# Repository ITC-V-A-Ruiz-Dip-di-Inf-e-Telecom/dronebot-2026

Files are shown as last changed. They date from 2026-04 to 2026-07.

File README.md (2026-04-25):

# Dronebot 2026 — Team Holly

Documentazione tecnica integrale del sistema di rilevamento fuoco e coordinamento rover per la gara Dronebot 2026.
Il sistema e' composto da due sottosistemi che comunicano via rete WiFi: uno **Script PC** per il rilevamento tramite drone DJI NEO 1, e un **Rover autonomo** guidato da Raspberry Pi 5 e Arduino Mega Keyestudio.

- **Istituto:** ITC Vincenzo Arangio Ruiz — Roma
- **Dipartimento:** Informatica e Telecomunicazioni
- **Team:** TEAM HOLLY

---

## Indice

1. [Come funziona](#come-funziona)
2. [Pipeline Completa del Sistema](#pipeline-completa-del-sistema)
3. [Pseudocodice](#pseudocodice)
4. [Il Rover Holly](#il-rover-holly)
5. [Firmware Arduino Mega V12.11](#firmware-arduino-mega-v1211)
6. [Script Raspberry Pi 5 V13.9](#script-raspberry-pi-5-v139)
7. [Configurazione OS Raspberry Pi](#configurazione-os-raspberry-pi)
8. [Prerequisiti](#prerequisiti)
9. [Installazione](#installazione)
10. [Connessione con RTMP live streaming](#connessione-con-rtmp-live-streaming)
11. [Connessione del dispositivo Android](#connessione-del-dispositivo-android)
12. [Configurazione PC](#configurazione)
13. [Utilizzo](#utilizzo)
14. [Generazione marker ArUco](#generazione-marker-aruco)
15. [BOM — Bill of Materials](#bom--bill-of-materials)
16. [SBOM — Software Bill of Materials](#sbom--software-bill-of-materials)
17. [Risoluzione problemi](#risoluzione-problemi)
18. [Licenza](#licenza)

---

## Come funziona

La gara si svolge in due fasi gestite automaticamente dallo script.

### Fase 1 — Rilevamento del fuoco

Il pilota porta il drone sull'area di fuoco. Lo script usa YOLO per rilevare il fuoco in tempo reale.
Quando la rilevazione e' stabile per `FIRE_CONFIR_FRAMES` frame consecutivi l'incendio viene confermato, viene salvata una foto come prova e viene inviato il **Segnale 1** al rover via HTTP.
Il rover riceve il segnale e inizia a prepararsi per il tracciamento.

### Fase 2 — Coordinamento rover

La Fase 2 puo' concludersi in due modi distinti, garantendo ridondanza operativa.

**Percorso A — Verifica automatica completa (primario)**

Il pilota torna nell'area del rover. Il rover inizia a seguire il drone tramite il LED IR. Il pilota riporta lentamente il drone sopra l'area di fuoco e lo mantiene fermo.

**Fase 2a — Blocco del cerchio:** Lo script rileva nuovamente il fuoco e, quando la posizione e' stabile per `FIRE_LOCK_FRAMES` frame consecutivi, blocca il centro e il raggio del cerchio di fuoco come riferimento preciso. Questo riferimento e' piu' accurato di quello della Fase 1 perche' il drone e' esattamente sopra il fuoco alla quota di verifica.

**Fase 2b — Verifica contenimento ArUco:** Lo script verifica che tutti e quattro gli angoli del marker ArUco montato sul rover siano all'interno del cerchio bloccato. Il centro del cerchio viene aggiornato frame per frame per compensare il leggero drift del drone in hovering. Quando la condizione e' soddisfatta per `ROVER_CONFIRM_FRAMES` frame consecutivi, il contenimento viene confermato, viene salvata la foto finale come prova e viene inviato `/stop` al rover via HTTP.

**Percorso B — Ridondanza passiva (se pilota esperto)**

Se le condizioni lo permettono, il rover segue il drone direttamente nell'area di fuoco senza passare per il lock o la verifica ArUco: le Fasi 2a e 2b vengono saltate interamente. Quando il drone esce dall'inquadratura, il thread `vision_logic` non rileva piu' il LED IR e imposta `comando_led = X`. Il rover si ferma autonomamente nella posizione corrente all'interno del cerchio di fuoco. I due percorsi sono indipendenti: la ridondanza garantisce il completamento anche in caso di perdita del segnale video.

---

## Pipeline Completa del Sistema

Il flusso completo dei dati, dall'acquisizione video del drone fino ai motori del rover.

### Lato PC

```mermaid
---
config:
  layout: elk
---
flowchart TD
    classDef drone stroke:#b45309,fill:#fef3c7,color:#78350f
    classDef comm stroke:#b91c1c,fill:#fee2e2,color:#7f1d1d
    classDef process stroke:#6d28d9,fill:#ede9fe,color:#4c1d95
    classDef phase stroke:#1d4ed8,fill:#dbeafe,color:#1e3a8a
    classDef evidence stroke:#15803d,fill:#dcfce7,color:#14532d

    DJI["DJI NEO 1\nDrone — camera gimbal"]:::drone
    FLY["DJI FLY\nApp Android\nAbilita Live Streaming RTMP"]:::comm
    FF["ffmpeg\nServer RTMP porta 1935\nRiceve video e scrive su v4l2"]:::process
    V4L["v4l2loopback\n/dev/video10\nWebcam virtuale nel kernel"]:::process
    MAIN["src/main.py\ncv2.VideoCapture\nLoop principale di rilevamento"]:::process

    DJI -->|video feed| FLY
    FLY -->|rtmp://IP_PC:1935/live/drone| FF
    FF -->|frame video| V4L
    V4L -->|VideoCapture| MAIN

    MAIN --> F1["FASE 1\nYOLOv8 rileva il fuoco\nConferma su 7 frame stabili\nFIRE_CONFIR_FRAMES = 7"]:::phase
    F1 -->|FUOCO CONFERMATO| EV1["Salva foto prova\nevidence/"]:::evidence
    EV1 --> S1["HTTP POST /start\nRaspberry Pi :5000\nRover inizia a muoversi"]:::comm

    S1 --> F2A["PERCORSO A — FASE 2a\nDrone ritorna sul fuoco\nAggancio preciso del cerchio\nFIRE_LOCK_FRAMES = 20"]:::phase
    S1 -.->|"PERCORSO B\nse rover gia' nell'area"| PASS["Drone esce dal frame\ncomando_led = X\nRover si ferma nell'area di fuoco\n2a e 2b saltate"]:::evidence
    F2A -->|CERCHIO AGGANCIATO| F2B["FASE 2b\nRileva marker ArUco sul rover\nVerifica che sia dentro il cerchio\nROVER_CONFIRM_FRAMES = 5"]:::phase
    F2B -->|CONTENIMENTO CONFERMATO| EV2["Salva foto finale\nevidence/"]:::evidence
    EV2 --> S2["HTTP POST /stop\nRaspberry Pi :5000"]:::comm
    S2 --> FIN["GARA COMPLETATA"]:::evidence
    PASS --> FIN
```

### Lato Rover

```mermaid
---
config:
  layout: elk
---
flowchart TD
    classDef raspberry stroke:#3730a3,fill:#e0e7ff,color:#1e1b4b
    classDef arduino stroke:#0f766e,fill:#ccfbf1,color:#134e4a
    classDef sensor stroke:#0369a1,fill:#bae6fd,color:#0c4a6e
    classDef control stroke:#6d28d9,fill:#ede9fe,color:#4c1d95
    classDef comm stroke:#b91c1c,fill:#fee2e2,color:#7f1d1d

    HTTP["/start ricevuto da PC\nstato_gara = IN_MARCIA"]:::comm

    subgraph RPI["Raspberry Pi 5 — holly_brain_v13.9.py"]
        VIS["Thread vision_logic\nPi Camera NoIR + Filtro R72\nrpicam-vid MJPEG\nThreshold 248 — blob LED IR\nposX determina direzione"]:::sensor
        LID["Thread lidar_thread\nYDLiDAR X4 Pro su /dev/ttyUSB0\nScansione 360 gradi a laser\nAggiorna punti_lidar ogni ciclo"]:::sensor
        LIST["Thread listener\nLegge telemetria da /dev/serial0\nFormato DATA:dF,dL,dR,dB,bSX,bDX\nAggiorna variabili globali ToF e bumper"]:::comm
        ADS_T["Thread ads_thread\nADS1115 via bus I2C\nMisura tensione batteria logica\nPartitore 10k/4.7k — ogni 1 secondo"]:::sensor
        ML["Main Loop 20 Hz\nFonde dati da tutti i thread\nApplica safety overrides\nDecide il comando finale"]:::control
    end
    class RPI raspberry

    HTTP --> RPI
    VIS -->|"posX<200 = A (sinistra)\nposX>440 = D (destra)\ncentro = W (avanti)\nnessun blob = X (stop)"| ML
    LID -->|punti_lidar 360 gradi| ML
    ADS_T -->|v_batteria| ML

    subgraph ARD["Arduino Mega — holly_mega_v12.11.ino"]
        TOF["4x Sensori VL53L0X ToF\nI2C indirizzi 0x30..0x33\nFrontale Destro Sinistro Posteriore\nDistanze in millimetri"]:::sensor
        BUMP["2x Bumper meccanici\npin 52 B_SX e pin 53 B_DX\nINPUT_PULLUP — LOW se premuto\nRilevamento urti fisici"]:::sensor
        VETO["VETO di Sicurezza Hardware\ndF<250mm o bumper premuto = STOP\ndB<200mm in retromarcia = STOP\ndL o dR<120mm in rotazione = STOP"]:::control
        DRV["L298N H-Bridge\nPWM su ENA pin10 e ENB pin5\nDirezione su IN1-IN4 pin 9-6\nVelocita' base vel=80 su 255"]:::control
        MOT["4x Motori DC 12V\nControllo differenziale\n2 motori SX e 2 motori DX"]:::control
    end
    class ARD arduino

    %% Feedback sensoriale verso VETO
    TOF -->|dF dL dR dB in mm| VETO
    BUMP -->|bSX bDX stato fisico| VETO
    VETO -->|comando sicuro| DRV
    DRV --> MOT

    %% Telemetria Arduino verso Raspberry Pi
    ARD -->|"DATA:dF,dL,dR,dB,bSX,bDX ogni 40ms"| LIST
    LIST -->|feedback ToF e bumper| ML

    %% Comando principale verso Arduino
    ML -->|"cmd_finale\nUART 115200 baud"| ARD
```

---

## Pseudocodice

### Script PC — Drone side (V13.x)

> **INIZIO**
>
> > Apri `VideoCapture` da `/dev/video10`
> >
> > Carica modello YOLOv8 `best.pt`
> >
> > Inizializza `ARUCODetector` — dizionario `DICT_4X4_50`, ID `10`
> >
> > Imposta `FASE = 1`
>
> **RIPETI all'infinito:**
>
> > Leggi frame dalla webcam virtuale
> >
> > SE frame non valido: `continua`
> >
> > **SE** `FASE == 1`:
> >
> > > Esegui YOLOv8 sul frame
> > >
> > > PER ogni detection con area `>= MIN_FIRE_AREA`:
> > >
> > > > Calcola spostamento centro rispetto al frame precedente
> > > >
> > > > SE spostamento `< MAX_FIRE_SHIFT`: `streak += 1`
> > > >
> > > > ALTRIMENTI: `streak = 0`
> > >
> > > SE `streak >= FIRE_CONFIR_FRAMES`:
> > >
> > > > Salva foto prova in `evidence/`
> > > >
> > > > `HTTP POST /start` → Raspberry Pi `:5000`
> > > >
> > > > `FASE = 2`
> >
> > **SE** `FASE == 2` E cerchio **non agganciato**:
> >
> > > Esegui YOLO → cerca detection con area `>= MIN_FIRE_AREA`
> > >
> > > SE trovata e spostamento stabile: `fire_lock_streak += 1`
> > >
> > > ALTRIMENTI: `fire_lock_streak = 0`
> > >
> > > SE `fire_lock_streak >= FIRE_LOCK_FRAMES`:
> > >
> > > > Calcola centro e raggio dalla bounding box
> > > >
> > > > Cerchio → **AGGANCIATO**
> >
> > **SE** `FASE == 2` E cerchio **agganciato**:
> >
> > > Aggiorna centro cerchio con nuova detection YOLO (drift compensation)
> > >
> > > Esegui `ARUCODetector` sul frame
> > >
> > > SE marker ArUco trovato:
> > >
> > > > SE tutti e 4 gli angoli sono nel cerchio: `rover_streak += 1`
> > > >
> > > > ALTRIMENTI: `rover_streak = 0`
> > > >
> > > > SE `rover_streak >= ROVER_CONFIRM_FRAMES`:
> > > >
> > > > > Salva foto finale in `evidence/`
> > > > >
> > > > > `HTTP POST /stop` → Raspberry Pi `:5000`
> > > > >
> > > > > **ESCI**
> >
> > Mostra frame a schermo
> >
> > SE tasto `ESC` o `Q`: **ESCI**
>
> **FINE**

---

### Firmware Arduino Mega (V12.11)

> **INIZIO**
>
> > Inizializza pin motori `ENA=10, ENB=5, IN1..IN4=9..6` come Output
> >
> > Inizializza pin bumper `B_SX=52, B_DX=53` come Input con Pull-up
> >
> > Porta tutti i pin XSHUT `14,15,16,17` a LOW — tutti i sensori spenti
> >
> > Avvia `Serial1` a 115200 baud verso Raspberry Pi
> >
> > Avvia bus I2C
> >
> > **AVVIO SEQUENZIALE SENSORI ToF:**
> >
> > > PER ogni sensore (Frontale, Destro, Sinistro, Posteriore):
> > >
> > > > Porta il pin XSHUT del sensore a HIGH
> > > >
> > > > Attendi 50 ms
> > > >
> > > > Assegna indirizzo I2C univoco `0x30, 0x31, 0x32, 0x33`
> > > >
> > > > Avvia lettura continua
>
> **RIPETI all'infinito:** (ciclo 40 ms ≈ 25 Hz)
>
> > Leggi `dF, dL, dR, dB` dai 4 sensori ToF in mm
> >
> > Leggi `bSX = (pin52 == LOW)`, `bDX = (pin53 == LOW)`
> >
> > SE `Serial1.available() > 0`: leggi carattere comando `(W, S, A, D, X)`
> >
> > ALTRIMENTI: mantieni l'ultimo comando ricevuto
> >
> > **VETO DI SICUREZZA:**
> >
> > > SE comando `W` E (`dF < 250` OPPURE `bSX` OPPURE `bDX`): `azione = X`
> > >
> > > SE comando `S` E `dB < 200`: `azione = X`
> > >
> > > SE comando `A` E `dL < 120`: `azione = X`
> > >
> > > SE comando `D` E `dR < 120`: `azione = X`
> > >
> > > ALTRIMENTI: `azione = comando`
> >
> > **ESECUZIONE MOVIMENTO:**
> >
> > > `W` → `muovi(+vel, +vel)` — avanti
> > >
> > > `S` → `muovi(-vel, -vel)` — indietro
> > >
> > > `A` → `muovi(-vel, +vel)` — rotazione sinistra
> > >
> > > `D` → `muovi(+vel, -vel)` — rotazione destra
> > >
> > > `Q` → `muovi(-vel/2, -vel)` — recupero baffo SX
> > >
> > > `E` → `muovi(-vel, -vel/2)` — recupero baffo DX
> > >
> > > `X` → `stoppa()`
> >
> > Invia su `Serial1`: `"DATA:dF,dL,dR,dB,bSX,bDX"`
> >
> > Attendi 40 ms
>
> **FINE**

---

### Script Raspberry Pi 5 (V13.9)

> **INIZIO**
>
> > Apri seriale `/dev/serial0` a 115200 baud verso Arduino
> >
> > Inizializza I2C → `ADS1115` canale A0
> >
> > `stato_gara = "ATTESA"`,  `punti_lidar = [5000] * 360`
> >
> > **AVVIA 5 THREAD DAEMON:**
> >
> > > `listener` — legge telemetria seriale dall'Arduino
> > >
> > > `vision_logic` — elabora frame camera, produce `comando_led`
> > >
> > > `lidar_thread` — legge scansione YDLiDAR 360°
> > >
> > > `ads_thread` — campiona tensione batteria ogni 1 s
> > >
> > > `run_flask` — serve dashboard web su porta 5000
>
> **MAIN LOOP** (20 Hz):
>
> > SE `stato_gara == "ATTESA"` OPPURE `comando_led == X`:
> >
> > > `cmd_finale = X`
> > >
> > > SE `b_sx` OPPURE `b_dx` OPPURE `timer_recupero > 0`:
> > >
> > > > SE `b_sx`: `(timer_recupero, last_side_hit) = (6, "SX")`
> > > >
> > > > SE `b_dx`: `(timer_recupero, last_side_hit) = (6, "DX")`
> > > >
> > > > `cmd_finale = Q` SE `last_side_hit == "SX"` ALTRIMENTI `E`
> > > >
> > > > `timer_recupero -= 1`
> >
> > ALTRIMENTI (IN_MARCIA e LED visibile):
> >
> > > `cmd_finale = comando_led`
> > >
> > > `dist_f_lidar = media(punti_lidar[175..185])`
> > >
> > > **A. Stop emergenza ToF frontale:**
> > >
> > > > SE `0 < tof_f < 100`: `cmd_finale = X`
> > >
> > > **B. ToF NUDGE — correzione laterale:**
> > >
> > > > SE `comando_led == W` E `0 < tof_l < 150`: `cmd_finale = D`
> > > >
> > > > SE `comando_led == W` E `0 < tof_r < 150`: `cmd_finale = A`
> > >
> > > **C. Aggiramento LiDAR:**
> > >
> > > > SE `cmd_finale == W` E `dist_f_lidar < 300`:
> > > >
> > > > > `varchi = [ang per ang in 130..230 se punti_lidar[ang] > 350]`
> > > > >
> > > > > SE varchi trovati: sterza verso il varco più vicino a 180°
> > > > >
> > > > > ALTRIMENTI: `cmd_finale = S`
> >
> > Scrivi `cmd_finale` sulla seriale → Arduino
> >
> > Attendi 50 ms
>
> **FINE**

---

## Il Rover Holly

Il rover e' un veicolo a 4 ruote motrici a controllo differenziale, progettato per seguire autonomamente il drone tramite una sorgente luminosa a infrarossi montata sul drone stesso.

### Architettura Hardware

```mermaid
---
config:
  layout: elk
---
flowchart TB
    classDef raspberry stroke:#3730a3,fill:#e0e7ff,color:#1e1b4b
    classDef arduino stroke:#0f766e,fill:#ccfbf1,color:#134e4a
    classDef sensor stroke:#0369a1,fill:#bae6fd,color:#0c4a6e
    classDef control stroke:#6d28d9,fill:#ede9fe,color:#4c1d95
    classDef power stroke:#b45309,fill:#fef3c7,color:#78350f

    subgraph LOGIC["Elettronica Logica — alimentata a 7.4V LiPo"]
        RPI5["Raspberry Pi 5\n8 GB RAM\nholy_brain_v13.9.py"]:::raspberry
        CAM["Pi Camera 3 NoIR Wide\nConnettore ISP\n+ Filtro Hoya R72 720nm\nIndividua il LED IR sul drone"]:::sensor
        LIDAR["YDLiDAR X4 Pro\n360 gradi 2D Laser\n/dev/ttyUSB0 USB\nEvita ostacoli in autonomia"]:::sensor
        ADS["ADS1115 16-bit ADC\nBus I2C — indirizzo 0x48\nMonitoraggio tensione batteria logica\nPartitore 10k/4.7k"]:::sensor
        BATT7["Batteria Logica\nLiPo 7.4V 2S 2700 mAh\nXell-Sport 30C"]:::power
        STEP["Step-Down XL4016E1\n7.4V a 5.2V 8A\nAlimenta tutta la logica"]:::control
        LS["Level Shifter Bidirezionale\n3.3V a 5V\nAdatta UART RPi-Arduino"]:::control
    end

    subgraph POWER["Elettronica Potenza — alimentata a 11.1V LiPo"]
        ARD["Arduino Mega Keyestudio\nholy_mega_v12.11.ino\nFirmware di basso livello"]:::arduino
        TOF["4x VL53L0X Time-of-Flight\nI2C 0x30 0x31 0x32 0x33\nFrontale Destro Sinistro Posteriore\nDistanze in millimetri"]:::sensor
        BUMP["2x Bumper meccanici\npin 52 B_SX e pin 53 B_DX\nRilevamento urti fisici diretti"]:::sensor
        L298["L298N H-Bridge\nMotor Driver duale\nGestisce 4 motori DC in coppia"]:::control
        MOT["4x Motori DC 12V\ncon ruote gommate\nControllo differenziale"]:::control
        BATT11["Batteria Potenza\nLiPo 11.1V 3S 1300 mAh\nXell-Light 20C"]:::power
    end

    CAM --- RPI5
    LIDAR --- RPI5
    ADS --- RPI5
    BATT7 --- ADS
    BATT7 --- STEP
    STEP -->|5.2V| RPI5
    RPI5 --- LS
    LS -->|UART 115200 baud| ARD
    ARD --- TOF
    ARD --- BUMP
    ARD --- L298
    L298 --- MOT
    BATT11 -->|11.1V diretti| L298
```

### Sistema di Alimentazione Duale

Il rover usa due batterie separate per isolare la logica dalla potenza:

| Batteria | Modello | Tensione | Uso |
|---|---|---|-----|
| Logica RPi | LiPo 7.4 V 2700 mAh 2S | 7.4 V → Step-Down → 5.2 V | Raspberry Pi 5 e sensori logici |
| Logica Arduino | LiPo 7.4 V 2200 mAh 2S | 7.4 V → Step-Down | Arduino Mega e periferiche |
| Potenza | Xell-Light 3S LiPo 11.1 V 1300 mAh | 11.1 V diretti | Motori DC 12 V tramite L298N |

Lo Step-Down XL4016E1 abbassa la tensione logica da 7.4 V a **5.2 V** (regolato con potenziometro per compensare il calo sotto carico e garantire stabilita' al Raspberry Pi 5). Il Level Shifter bidirezionale 3.3V ↔ 5V adatta i livelli logici della linea UART tra i due microcontrollori. L'ADS1115 monitora in tempo reale la tensione della batteria logica tramite un partitore resistivo (10 kΩ / 4.7 kΩ).

Sul connettore di bilanciamento della batteria logica RPi (7.4 V 2S) e' collegato un **tester LiPo con buzzer** impostato a **3.4 V per cella** come soglia di allarme sonoro: quando una delle celle scende sotto questa soglia il buzzer suona avvisando il team prima che la tensione raggiunga livelli critici per il Raspberry Pi.

### Sistema di Visione — Tracciamento LED IR

La logica di inseguimento sfrutta la combinazione di una telecamera priva di filtro IR (NoIR) e un filtro ottico passa-alto (Hoya R72, soglia 720 nm) per rendere visibile **solo** la luce infrarossa. Un singolo LED IR da 210 mW montato sul drone appare come l'unico punto luminoso nell'immagine, anche in ambienti illuminati.

```mermaid
---
config:
  layout: elk
---
flowchart TD
    classDef sensor stroke:#0369a1,fill:#bae6fd,color:#0c4a6e
    classDef process stroke:#6d28d9,fill:#ede9fe,color:#4c1d95
    classDef decision stroke:#b45309,fill:#fef3c7,color:#78350f
    classDef command stroke:#b91c1c,fill:#fee2e2,color:#7f1d1d
    classDef stop stroke:#374151,fill:#f1f5f9,color:#1f2937

    CAM["Pi Camera 3 NoIR Wide\nSensore senza filtro IR incorporato\nCaptura anche la luce infrarossa"]:::sensor
    FILT["Filtro Hoya R72 — 720nm\nBlocca tutta la luce visibile\nLascia passare solo l'infrarosso\nIl LED IR sul drone diventa l'unico punto luminoso"]:::sensor
    GRAY["rpicam-vid MJPEG\nFrame convertito in Grayscale 640x480\nBassa latenza per inseguimento real-time"]:::process
    THR["cv2.threshold — soglia 248\nSeleziona solo i pixel piu' luminosi\nElimina il rumore ambientale"]:::process
    MASK["Maschera binaria\nRegioni bianche = sorgenti IR intense\nTutto il resto = nero"]:::process
    CNT["cv2.findContours\nIndividua le regioni connesse\nOrdinate per area decrescente"]:::process
    AREA{"Area blob valida?\n15 px < area < 2000 px\nSoglia anti-rumore e anti-saturazione"}:::decision
    STOP["comando_led = X\nSTOP — LED assente\no blob troppo grande o piccolo"]:::stop
    POS["Calcola centroide\nposX = M10 diviso M00\nPosizione orizzontale del LED nel frame"]:::process
    L{"posX < 200?\nLED nel terzo sinistro"}:::decision
    A["comando_led = A\nSterzata sinistra\nIl rover ruota per centrare il LED"]:::command
    R{"posX > 440?\nLED nel terzo destro"}:::decision
    D["comando_led = D\nSterzata destra\nIl rover ruota per centrare il LED"]:::command
    W["comando_led = W\nAvanti dritto\nLED nella zona centrale 200..440 px"]:::command

    CAM -->|frame raw| FILT
    FILT --> GRAY
    GRAY --> THR
    THR --> MASK
    MASK --> CNT
    CNT --> AREA
    AREA -->|No — LED non rilevato| STOP
    AREA -->|Si — blob valido| POS
    POS --> L
    L -->|Si| A
    L -->|No| R
    R -->|Si| D
    R -->|No| W
```

---

## Firmware Arduino Mega V12.11

File: `rover/arduino/holly_mega_v12.11.ino`

### Pinout Completo

| Categoria | Pin | Funzione |
|---|-----|---|
| Motori L298N | 10, 5 | ENA, ENB — velocita' PWM (0–255) |
| Motori L298N | 9, 8 | IN1, IN2 — direzione motore SX |
| Motori L298N | 7, 6 | IN3, IN4 — direzione motore DX |
| ToF XSHUT | 14 | X_F — accensione sensore Frontale |
| ToF XSHUT | 15 | X_R — accensione sensore Destro |
| ToF XSHUT | 16 | X_L — accensione sensore Sinistro |
| ToF XSHUT | 17 | X_B — accensione sensore Posteriore |
| Serial1 | 18 | TX1 — trasmissione verso Raspberry Pi (via Level Shifter bidirezionale) |
| Serial1 | 19 | RX1 — ricezione da Raspberry Pi (via Level Shifter bidirezionale) |
| Bumper | 52 | B_SX — micro-switch sinistro (INPUT_PULLUP) |
| Bumper | 53 | B_DX — micro-switch destro (INPUT_PULLUP) |

### Inizializzazione ToF (Risoluzione Conflitti I2C)

Tutti i sensori VL53L0X escono dalla fabbrica con lo stesso indirizzo I2C (`0x29`). Per distinguerli sul bus, il firmware li accende uno alla volta:

```cpp
void initTof(VL53L0X &s, int pin_xshut, uint8_t nuovo_indirizzo) {
    digitalWrite(pin_xshut, HIGH);  // accende solo questo sensore
    delay(50);
    if (s.init()) {
        s.setAddress(nuovo_indirizzo); // assegna indirizzo univoco
        s.setTimeout(200);
        s.startContinuous();
    }
}
// Avvio sequenziale:
// initTof(sF, X_F, 0x30)  → Frontale
// initTof(sR, X_R, 0x31)  → Destro
// initTof(sL, X_L, 0x32)  → Sinistro
// initTof(sB, X_B, 0x33)  → Posteriore
```

### Logica VETO — Sicurezza Hardware

Il VETO e' la funzione di sicurezza piu' critica: sovrascrive i comandi ricevuti dal Raspberry Pi prima che arrivino ai motori. Opera a livello firmware senza ritardi di rete.

| Condizione | Soglia | Azione |
|---|---|---|
| Comando `W` + `dF < 250 mm` | 25 cm | Forza `X` (stop) |
| Comando `W` + bumper premuto | — | Forza `X` (stop) |
| Comando `S` + `dB < 200 mm` | 20 cm | Forza `X` (stop) |
| Comando `A` + `dL < 120 mm` | 12 cm | Forza `X` (stop) |
| Comando `D` + `dR < 120 mm` | 12 cm | Forza `X` (stop) |

La soglia laterale e' volutamente piu' bassa (12 cm vs 25 cm) per permettere manovre in corridoi stretti.

### Controllo Motori

```cpp
void muovi(int sinistra, int destra) {
    digitalWrite(IN1, sinistra > 0 ? LOW : HIGH);
    digitalWrite(IN2, sinistra > 0 ? HIGH : LOW);
    analogWrite(ENA, abs(sinistra));

    digitalWrite(IN3, destra > 0 ? LOW : HIGH);
    digitalWrite(IN4, destra > 0 ? HIGH : LOW);
    analogWrite(ENB, abs(destra));
}
```

Mappa comandi → velocita':

| Carattere | `muovi(L, R)` | Moto effettivo |
|---|---|---|
| `W` | `(+80, +80)` | Avanti diritto |
| `S` | `(-80, -80)` | Indietro |
| `A` | `(-80, +80)` | Rotazione sinistra (perno) |
| `D` | `(+80, -80)` | Rotazione destra (perno) |
| `Q` | `(-40, -80)` | Retromarcia assistita SX (recupero baffo) |
| `E` | `(-80, -40)` | Retromarcia assistita DX (recupero baffo) |
| `X` | stop | Stop motori |

I comandi `Q` ed `E` ruotano il rover all'indietro con velocita' asimmetrica per liberarsi da un angolo dopo l'urto di un baffo.

### Telemetria

Al termine di ogni ciclo Arduino invia una stringa sulla Serial1:

```
DATA:250,150,150,500,0,0
      │    │    │    │  │  └── b_DX (0=libero, 1=premuto)
      │    │    │    │  └───── b_SX
      │    │    │    └──────── dB posteriore [mm]
      │    │    └───────────── dR destro [mm]
      │    └────────────────── dL sinistro [mm]
      └─────────────────────── dF frontale [mm]
```

Il timeout del sensore ToF e' impostato a 200 ms; se il sensore non risponde il valore tipico di errore e' 8190 mm (da ignorare).

---

## Script Raspberry Pi 5 V13.9

File: `rover/raspberry/holly_brain_v13.9.py`

Lo script e' il "cervello" del rover. Coordina in parallelo cinque thread indipendenti piu' il main loop.

### Thread Architecture

| Thread | Funzione | Frequenza |
|---|---|---|
| `listener` | Legge telemetria seriale dall'Arduino | ~25 Hz (bloccante) |
| `vision_logic` | Elabora frame camera, produce `comando_led` | ~20 fps |
| `lidar_thread` | Legge scansione YDLiDAR 360° | ~5 Hz |
| `ads_thread` | Monitora tensione batteria logica | 1 Hz |
| `run_flask` | Serve dashboard web e stream video | event-driven |
| **Main loop** | Applica safety overrides, invia cmd ad Arduino | 20 Hz |

### Logica di Navigazione a Livelli

La navigazione usa quattro livelli sovrapposti di sicurezza, dal piu' veloce (hardware) al piu' lento (software):

**Livello 0 — Arduino VETO** (firmware, ~25 Hz)
Reagisce in tempo reale ai ToF e bumper. Nessun ritardo di rete. Non bypassabile dal software.

**Livello 1 — ToF NUDGE** (Raspberry, ~20 Hz)
Se il rover sta andando avanti (`W`) e un ToF laterale rileva un ostacolo a meno di 15 cm, sterzata attiva verso il lato libero. Corregge la traiettoria prima che scatti il VETO Arduino.

**Livello 2 — LiDAR Avoidance** (Raspberry, ~20 Hz)
Se la media dei punti LiDAR nell'arco 175°..185° e' inferiore a 30 cm, cerca un "varco" (distanza > 35 cm) nell'arco 130°..230°. Se trovato sterza verso il varco piu' vicino ai 180°; altrimenti retromarcia.

**Livello 3 — Recupero Bumper** (Raspberry, ~20 Hz)
Urto meccanico → retromarcia asimmetrica `Q`/`E` per 6 cicli (0.3 s). Scavalca tutti gli altri comandi per la durata del recupero.

### Flask — Dashboard e API

La dashboard web e' accessibile all'indirizzo `http://<IP_ROVER>:5000` da qualsiasi browser sulla stessa rete WiFi.

**Accesso via SSH (consigliato in gara):** Se non si e' sulla stessa rete del rover ma si ha accesso SSH, creare un tunnel locale:

```bash
ssh -L 5000:localhost:5000 ruiz@<IP_ROVER>
```

Poi aprire `http://localhost:5000` nel browser del PC. Il tunnel rimane attivo finche' la sessione SSH e' aperta.

| Route | Metodo | Funzione |
|---|---|---|
| `/` | GET | Pagina HTML con dashboard e video |
| `/start` | POST | Avvia la gara (`stato_gara = "IN_MARCIA"`) |
| `/stop` | POST | Ferma la gara (`stato_gara = "ATTESA"`) |
| `/telemetria` | GET | JSON con stato, batteria, ToF, bumper, cmd |
| `/video_feed` | GET | Stream MJPEG dalla Pi Camera |

L'endpoint `/start` e' chiamato automaticamente dallo script PC quando il fuoco viene confermato in Fase 1. L'endpoint `/stop` viene chiamato quando il rover entra nel cerchio in Fase 2b.

### Monitoraggio Batteria (ADS1115)

L'ADS1115 e' un convertitore analogico-digitale a 16 bit collegato via I2C. Legge la tensione ridotta da un partitore resistivo (10 kΩ / 4.7 kΩ) collegato alla batteria logica 7.4 V.

```python
v_su_a0 = chan.voltage          # tensione sul pin A0 dell'ADS
v_batteria = v_su_a0 * 3.082   # coefficiente partitore = (10k + 4.7k) / 4.7k
```

Il Raspberry Pi 5 non ha pin ADC nativi, quindi l'ADS1115 esterno e' necessario per questa funzione.

---

## Configurazione OS Raspberry Pi

Sistema Operativo: **Raspberry Pi OS Lite 64-bit**

### Modifiche a `/boot/firmware/config.txt`

```ini
# Corrente USB massima (necessaria per alimentare YDLiDAR via USB)
usb_max_current_enable=1

# Abilita bus I2C per ADS1115
dtparam=i2c_arm=on

# Abilita UART per comunicazione con Arduino
enable_uart=1
```

Dopo la modifica, eseguire `sync` prima del riavvio per garantire la scrittura su SD.

### Verifica Hardware al Boot

```bash
# Verifica che l'ADS1115 sia rilevato sul bus I2C (address 0x48)
sudo modprobe i2c-dev
i2cdetect -y 1

# Monitoraggio salute sistema in tempo reale
watch -n 0.5 "vcgencmd get_throttled && vcgencmd measure_volts core && vcgencmd measure_temp"
```

### Servizio Systemd (Avvio Automatico)

Il rover si avvia automaticamente al boot tramite un servizio systemd.

```ini
# /etc/systemd/system/holly_rover.service
[Unit]
Description=Rover Holly V13.9
After=network.target

[Service]
ExecStart=/home/ruiz/rover_project/env/bin/python3 /home/ruiz/rover_project/holly_brain_v13.9.py
WorkingDirectory=/home/ruiz/rover_project
Restart=always
User=ruiz

[Install]
WantedBy=multi-user.target
```

```bash
# Abilita avvio al boot
sudo systemctl enable holly_rover.service

# Avvio manuale
sudo systemctl start holly_rover.service

# Verifica stato (deve apparire "active (running)" in verde)
sudo systemctl status holly_rover.service

# Log in tempo reale
journalctl -u holly_rover.service -f
```

### Protezione Scheda SD (OverlayFS)

Per prevenire la corruzione della scheda SD in caso di spegnimento improvviso, il filesystem root viene montato in modalita' overlay (read-only con write layer volatile in RAM). **Ogni modifica fatta con l'overlay attivo viene persa al riavvio.**

#### Verifica stato attuale

```bash
mount | grep "on / "
# Output (rw,...): filesystem scrivibile — modalita' sviluppo
# Output (overlay on / type overlay): protetto — modalita' gara

mount | grep /boot/firmware
# Deve essere rw per poter cambiare le impostazioni dell'overlay
```

#### Procedura 1 — Blocco (Modalita' Gara, read-only)

Da eseguire prima di scendere in pista per proteggere la SD da cali di tensione.

```bash
sudo raspi-config
# Performance Options -> Overlay File System -> Yes (Abilita)
# Alla domanda sulla partizione di boot -> Yes (Proteggi)

sync          # forza la scrittura di tutti i dati pendenti
sudo reboot
```

#### Procedura 2 — Sblocco (Modalita' Sviluppo, read-write)

Da eseguire per installare librerie, modificare script o configurare hardware.

**Metodo A — Standard:**

```bash
sudo raspi-config
# Performance Options -> Overlay File System -> No (Disabilita)
# Alla domanda sulla partizione di boot -> Yes (Rendi scrivibile)
sudo reboot
```

**Metodo B — Forzato (se il menu da' errore "Read-only"):**

```bash
sudo mount -o remount,rw /boot/firmware
sudo raspi-config nonint do_overlayfs 1
sudo reboot
```

> [!NOTE]
> Usa sempre `sync` dopo aver modificato script importanti e prima di attivare il blocco. Quando l'overlay e' attivo, i file creati o modificati spariscono al riavvio: assicurati di essere in modalita' RW prima di lavorare sul codice.

---

## Prerequisiti

**PC:**

- **Pixi** — gestore di pacchetti: https://pixi.prefix.dev/latest/
- **scrcpy** — streaming schermo Android: `apt install scrcpy` (Debian/Ubuntu)
- **adb** — Android Debug Bridge (incluso con scrcpy o installabile via package manager)
- **v4l2loopback** — modulo kernel per la webcam virtuale
- **Dispositivo Android** con debug USB abilitato

**Rover:**

- Raspberry Pi OS Lite 64-bit configurato come descritto sopra
- Python 3.11+ con ambiente virtuale
- `rpicam-vid` (incluso in Raspberry Pi OS)
- Driver YDLiDAR Python

---

## Installazione

### 1. Dipendenze Python e PyTorch con supporto GPU

Lo script `pc/setup_pytorch.sh` installa le dipendenze pixi, rimuove PyTorch CPU-only e installa PyTorch con supporto CUDA 12.1:

```bash
cd pc
pixi install
./setup_pytorch.sh
```

**Verifica che CUDA funzioni:**

```bash
pixi run python -c "import torch; print('CUDA:', torch.cuda.is_available()); print('GPU:', torch.cuda.get_device_name(0) if torch.cuda.is_available() else 'N/A')"
```

### 2. Server RTMP con ffmpeg

Lo script `pc/setup_ffmpeg_rtmp.sh` avvia il server RTMP che riceve il video da DJI FLY e lo scrive sulla webcam virtuale:

```bash
./setup_ffmpeg_rtmp.sh
```

Equivale a:

```bash
ffmpeg -fflags nobuffer -flags low_delay -listen 1 -i rtmp://0.0.0.0:1935/live/drone -f v4l2 /dev/video10
```

### 3. Creare la webcam virtuale

Lo script `pc/setup_virtual_camera.sh` carica il modulo kernel v4l2loopback e crea il dispositivo `/dev/video10`:

```bash
sudo ./setup_virtual_camera.sh
```

Oppure manualmente:

```bash
sudo modprobe v4l2loopback devices=1 video_nr=10 card_label="PhoneCam" exclusive_caps=1
```

Il numero del dispositivo puo' essere cambiato modificando anche `VIDEO_SOURCE` in `src/config.py`.

**Su Fedora / RHEL (v4l2loopback non disponibile di default):**

```bash
sudo dnf install https://mirrors.rpmfusion.org/free/fedora/rpmfusion-free-release-$(rpm -E %fedora).noarch.rpm
sudo dnf install v4l2loopback akmod-v4l2loopback
sudo akmods --force
sudo depmod -a
sudo reboot
sudo modprobe v4l2loopback devices=1 video_nr=10 card_label="PhoneCam" exclusive_caps=1
```

---

> [!NOTE]
> Per i metodi con RTMP o Wireless entrambi i dispositivi devono essere collegati alla stessa rete

## Connessione con RTMP live streaming

L'applicazione DJI FLY supporta il live streaming del video feed via RTMP, questo permette di usare
un qualsiasi dispositivo Ios o Android.

1. Creare un server RTMP sul proprio dispositivo con ffmpeg
```bash
 ffmpeg -fflags nobuffer -flags low_delay -listen 1 -i rtmp://0.0.0.0:1935/live/drone -f v4l2 /dev/video10
```

2. Nell'app DJI FLY premere GO FLY per connettersi al drone
3. Aprire le impostazioni di *trasmissione* > *live streaming platforms* e selezionare *RTMP*
4. Inserire il live streaming address definito nel comando ffmpeg,cambiando l'indirizzo IP con quello del nostro dispositivo

```bash
ip a | grep "inet " | grep -v 127
```
L'output dara una stringa come : inet 172.20.10.5/28 brd 172.20.10.15 scope global dynamic noprefixroute wlp4s0
Il primo indirizzo ip andra` sostituito quando l'indirizzo rtmp verra inserito nell'app DJI

5. Selezionare la risoluzione e bitrate piu adatti
6. Iniziare la live

## Connessione del dispositivo Android

### Connessione via cavo USB (consigliata per la configurazione iniziale)

1. Abilitare il debug USB sul dispositivo Android: Impostazioni > Opzioni sviluppatore > Debug USB
2. Collegare il cavo USB al PC
3. Verificare la connessione:

```bash
adb devices
```

L'output deve mostrare il dispositivo con stato `device`. Se compare `unauthorized`, sbloccare il telefono e accettare il dialogo di autorizzazione.

4. Avviare lo streaming:

```bash
scrcpy --v4l2-sink=/dev/video10 --no-playback
```

### Connessione wireless (necessaria durante la gara)

La connessione wireless e' necessaria perche' durante la gara il drone deve muoversi liberamente senza cavo.

**Metodo 1 — ADB over TCP/IP (Android standard):**

Con il cavo USB ancora collegato, eseguire:

```bash
adb tcpip 5555
```

Trovare l'indirizzo IP del telefono: Impostazioni > WiFi > (nome rete) > Indirizzo IP.

Disconnettere il cavo USB, poi:

```bash
adb connect <IP_TELEFONO>:5555
adb devices
scrcpy --v4l2-sink=/dev/video10 --no-playback
```

Se la connessione si perde, ricollegare con:

```bash
adb connect <IP_TELEFONO>:5555
```

**Metodo 2 — Debug wireless nativo (Android 11+):**

Su Android 11 o superiore e' disponibile il debug wireless nativo.

Abilitare: Impostazioni > Opzioni sviluppatore > Debug wireless.

Abbinamento tramite codice di coppia:

```bash
adb pair <IP_TELEFONO>:<PORTA_ABBINAMENTO>
```

Poi connettersi alla porta di debug wireless mostrata nell'interfaccia:

```bash
adb connect <IP_TELEFONO>:<PORTA_DEBUG>
adb devices
scrcpy --v4l2-sink=/dev/video10 --no-playback
```

**Opzioni scrcpy utili per la connessione wireless:**

```bash
# Ridurre la risoluzione per migliorare la stabilita' su WiFi lento
scrcpy --v4l2-sink=/dev/video10 --no-playback --max-size=1024

# Ridurre il bitrate
scrcpy --v4l2-sink=/dev/video10 --no-playback --video-bit-rate=2M

# Entrambe
scrcpy --v4l2-sink=/dev/video10 --no-playback --max-size=1024 --video-bit-rate=2M
```

---

## Configurazione

Tutti i parametri si trovano in `src/config.py`.

```python
VIDEO_SOURCE = "/dev/video10"       # dispositivo webcam virtuale

# Fase 1
YOLO_CONFIDENCE = 0.70             # soglia di confidenza YOLO (0.0 - 1.0)
FIRE_CONFIR_FRAMES = 7             # frame consecutivi per confermare il fuoco
MIN_FIRE_AREA = 5000               # area minima in pixel del fuoco rilevato
MAX_FIRE_SHIFT = 100               # spostamento massimo centro fuoco tra frame

# Fase 2
FIRE_LOCK_FRAMES = 20              # frame stabili per bloccare il cerchio di fuoco
ROVER_CONFIRM_FRAMES = 5           # frame consecutivi per confermare il contenimento
MAX_ROVER_SHIFT = 15               # tolleranza in pixel aggiunta al raggio del cerchio

# Comunicazione rover
RASPBERRY_PI_URL = "http://192.168.1.57:5000"  # IP del Raspberry Pi
```

---

## Utilizzo

### 1. Assicurarsi che la webcam virtuale sia attiva

```bash
sudo modprobe v4l2loopback devices=1 video_nr=10 card_label="PhoneCam" exclusive_caps=1
```

### 2. Connettere il telefono e avviare lo streaming

```bash
# Via cavo
scrcpy --v4l2-sink=/dev/video10 --no-playback

# Via WiFi (dopo aver configurato adb wireless)
adb connect <IP_TELEFONO>:5555
scrcpy --v4l2-sink=/dev/video10 --no-playback
```

### 3. Avviare lo script

```bash
cd dronebot-2026/pc
pixi run python src/main.py
```

Lo script deve essere avviato **dopo** scrcpy, altrimenti OpenCV non trovera' il dispositivo video.

### Controlli

- `ESC` o `Q` — chiude l'applicazione

### Output

- Feed video in tempo reale con i box di rilevamento
- Pannello informativo in alto con fase corrente, streak e FPS
- Cerchio di fuoco sovrapposto durante la Fase 2
- Box del rover colorato in verde (contenuto) o rosso (non contenuto)
- Foto salvate automaticamente nella cartella `evidence/` alla conferma del fuoco e al completamento della gara

---

## Generazione marker ArUco

Per generare il marker ArUco da stampare e montare sul rover:

```bash
pixi run python src/aruco_generator.py
```

Il marker viene salvato come `aruco_marker.png`. Verificare che il dizionario e l'ID corrispondano a quelli in `config.py` (`ARUCO_DICTIONARY_NAME`, `ARUCO_ID`).

---

## BOM — Bill of Materials

Vedi [`BILL_OF_MATERIALS.md`](BILL_OF_MATERIALS.md) per la lista completa dei 18 componenti con prezzi (totale € 477,58).

> [!NOTE]
> Il drone DJI NEO 1 e' fornito dall'organizzazione della gara e non e' incluso nel BOM.

---

## Schemi

Vedi [`Technical_Diagram.jpg`](Technical_Diagram.jpg) per il diagramma tecnico del rover (schema meccanico e wiring diagram).

---

## SBOM — Software Bill of Materials

Vedi [`SBOM.md`](SBOM.md) per la lista completa delle librerie e dipendenze software di PC, Raspberry Pi e Arduino.

---

## Risoluzione problemi

### CUDA non disponibile (interfaccia mostra CPU)

```bash
pixi run pip uninstall torch torchvision -y
pixi run pip install torch torchvision --index-url https://download.pytorch.org/whl/cu121
```

### `/dev/video10` non trovato

```bash
# Verificare i dispositivi video presenti
ls -l /dev/video*

# Verificare se il modulo e' caricato
lsmod | grep v4l2loopback

# Ricaricare il modulo
sudo rmmod v4l2loopback
sudo modprobe v4l2loopback devices=1 video_nr=10 card_label="PhoneCam" exclusive_caps=1
```

### Il dispositivo esiste ma non funziona

```bash
# Verificare se un processo occupa gia' il dispositivo
sudo fuser /dev/video10

# Aggiungere il proprio utente al gruppo video (se problemi di permessi)
sudo usermod -aG video $USER
# Effettuare logout e login per applicare la modifica
```

### adb non trova il dispositivo

```bash
adb kill-server
adb start-server
adb devices
```

### Connessione wireless instabile

Assicurarsi che PC e telefono siano sulla stessa rete WiFi. Usare `--max-size=1024 --video-bit-rate=2M` con scrcpy per ridurre il carico di rete. Se la connessione si interrompe durante la gara, riconnettersi con `adb connect <IP>:5555` e riavviare scrcpy.

### Il rover non riceve il segnale di avvio

Verificare che `RASPBERRY_PI_URL` in `src/config.py` corrisponda all'indirizzo IP attuale del Raspberry Pi. Testare la raggiungibilita':

```bash
curl -X POST http://<IP_ROVER>:5000/start
```

### I sensori ToF non si inizializzano

Se Arduino non riesce ad inizializzare i ToF, verificare i collegamenti SDA/SCL e i pin XSHUT. In caso di indirizzo bloccato, spegnere e riaccendere l'Arduino per resettare tutti i ToF all'indirizzo di default `0x29`.

### Il rover non segue il drone

Verificare che il filtro Hoya R72 sia montato correttamente sulla Pi Camera. Testare la visione dalla dashboard aprendo `/video_feed` nel browser: il LED IR del drone deve apparire come un punto bianco brillante su sfondo scuro. Se l'immagine e' completamente nera, verificare l'accensione del LED IR. Se e' completamente bianca, il filtro non e' montato.

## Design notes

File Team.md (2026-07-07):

# Team Holly: Organigramma & Workflow

Il successo del progetto Holly (ITC V. Arangio Ruiz, Roma) nasce dalla sinergia tra diverse aree di specializzazione integrate:

## Leadership & Supervision

- **Prof. Riccardo Annolfi**: Technical Project Supervisor & Research Lead https://github.com/RicAnn
- **Prof.ssa Giselda De Vita**: Academic Coordinator & Project Coordinator
- **Prof.ssa Guglielmina Uliano**: Head of School & Institutional Supervisor

## Student Team
- **Raffaele Meo (Project Lead & Architect)**: Coordinamento software (Raspberry/PC), Visione AI (YOLO/OpenCV) e gestione flussi RTMP.
- **Davide Dubaldi (System Integration)**: Progettazione 3D, meccanica del Rover e integrazione moduli hardware.
- **Gabriel Priamo (Hardware Engineering)**: Monitoraggio flussi dati, telemetria e gestione del rilascio software.
- **Gianmarco D'Angelis (Embedded Systems)**: Gestione Power System, cablaggi, sensori ToF e affidabilità elettrica.
- **Ibrahim Ouaoujaout (Deployment & Telemetry)**: Sviluppo firmware Arduino Mega, logiche di sicurezza (Veto) e controllo motori. Pilota Drone.

## Regole operative
Il team adotta una metodologia di sviluppo strutturata tramite GitHub per il tracciamento dei task e Milestone dedicate per ogni fase del progetto (Foundation, Safety, Integration), garantendo stabilità e documentazione continua in vista della competizione Dronebot 2026.

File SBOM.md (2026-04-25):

# SBOM — Software Bill of Materials

Lista completa delle librerie e dipendenze software utilizzate nel progetto Dronebot 2026 — Team Holly.

---

## PC — Script di Rilevamento

Gestito con **Pixi** (conda-forge + pip). File di riferimento: `pc/pixi.toml`.

| Pacchetto | Versione | Uso |
|---|---|-----|
| Python | 3.12.x | Linguaggio base |
| ultralytics | >= 8.0.0 | YOLOv8 — rilevamento fuoco in tempo reale |
| opencv | >= 4.10.0 | Acquisizione video, rilevamento ArUco, rendering |
| pytorch | >= 2.0.0 | Backend inferenza neurale (+ CUDA 12.1) |
| torchvision | >= 0.15.0 | Trasformazioni immagine per YOLOv8 |
| numpy | >= 1.24 | Calcoli geometrici (cerchio di fuoco, distanze) |
| requests | (via pip) | HTTP POST verso il server Flask del rover |
| rich | >= 13.0.0 | Output console formattato |
| python-dotenv | >= 1.0.0 | Gestione variabili d'ambiente |
| v4l2loopback | kernel module | Webcam virtuale `/dev/video10` |
| scrcpy | sistema (apt/pacman) | Streaming schermo Android verso v4l2 |
| ffmpeg | sistema | Server RTMP per streaming da DJI FLY |
| adb | sistema | Android Debug Bridge |

---

## Rover — Raspberry Pi 5

Sistema Operativo: **Raspberry Pi OS Lite 64-bit**.
Gestito con **Python venv**. Avvio automatico tramite systemd (`holly_rover.service`).

### Pacchetti di Sistema (apt)

| Pacchetto | Uso |
|---|-----|
| python3-pip | Gestore pacchetti Python |
| i2c-tools | Diagnostica bus I2C (`i2cdetect`) |
| git | Version control |
| libcamera-dev | Librerie fotocamera Raspberry Pi |

### Librerie Python (pip / venv)

| Pacchetto | Versione | Uso |
|---|---|-----|
| Python | 3.11+ | Linguaggio base |
| Flask | >= 2.x | Dashboard web, API REST (`/start`, `/stop`, `/telemetria`) |
| pyserial | >= 3.x | Comunicazione seriale UART con Arduino Mega |
| opencv-headless | >= 4.x | Elaborazione frame MJPEG, threshold, findContours |
| numpy | >= 1.24 | Calcoli LiDAR (media punti, ricerca varchi) |
| ydlidar | Python SDK | Interfaccia YDLiDAR X4 Pro su `/dev/ttyUSB0` |
| adafruit-ads1x15 | >= 2.x | Driver ADS1115 16-bit ADC via I2C |
| adafruit-blinka | >= 8.x | HAL hardware Adafruit per Raspberry Pi |

### Tool di Sistema

| Tool | Uso |
|---|-----|
| rpicam-vid | Acquisizione MJPEG dalla Pi Camera 3 NoIR Wide |
| systemd | Avvio automatico al boot (`holly_rover.service`) |

---

## Rover — Arduino Mega Keyestudio

Firmware: `rover/arduino/holly_mega_v12.11.ino`
IDE: **Arduino IDE** (versione 2.x).
Librerie installate tramite Arduino IDE Library Manager:

| Libreria | Versione | Autore | Uso |
|---|---|---|-----|
| Wire | built-in | Arduino | Bus I2C per comunicazione con i 4 sensori ToF VL53L0X |
| VL53L0X | >= 1.3.x | Pololu | Driver sensori Time-of-Flight — distanze in mm |

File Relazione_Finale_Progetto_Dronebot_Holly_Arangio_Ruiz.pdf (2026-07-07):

# Sviluppo e Implementazione di Algoritmi di Visione Artificiale, Integration Testing e Edge AI per Piattaforme Robotiche Autonome: Il Caso Studio “Rover Holly”

Istituto: I.T.C. “Vincenzo Arangio Ruiz” — Roma
Dirigente Scolastico (Head of School): Prof.ssa Guglielmina Uliano
Dipartimento: Informatica e Telecomunicazioni
Tipologia di allegato: Produzione di materiale didattico integrato e documentazione scientifico-tecnologica di contenuti digitali applicati (L.16/05/77 n. 306)

Autori e Contributi Scientifici

Prof. Riccardo Annolfi — Autore Principale e Responsabile della Ricerca (Ingegnerizzazione del software core del Rover, threading concorrente su Raspberry Pi 5, firmware ad anello chiuso su Arduino Mega, supervisione dell’integrazione di sistema e Power Architecture). Raffaele Meo — Co-Autore e Lead Image Processing Developer (Sviluppo dell’algoritmo di visione artificiale lato PC di terra, modellizzazione dei tensori YOLOv8, tracciamento dei marker ArUco e gestione flussi streaming RTMP).

Team di Supporto allo Sviluppo (Student Lab Co-Design)

Prof.ssa Giselda De Vita: Coordinamento didattico e istituzionale di progetto.
Ibrahim Ouadjaout: Supporto allo sviluppo del firmware di Arduino Mega e condotta di volo del drone.
Davide D’Ubaldi: Progettazione meccanica 3D del telaio e integrazione moduli hardware.
Gianmarco D’Angelis: Sviluppo del Power System e cablaggi di potenza.
Gabriel Priamo: Monitoraggio dei flussi di telemetria e gestione del rilascio software.

Nota di merito: Il presente progetto è stato insignito del Premio per il Progetto e l’Innovazione Tecnologica in occasione della Rome-Cup 2026, a riconoscimento dell’eccellenza nelle soluzioni di Edge AI applicate alla robotica autonoma.

## Abstract

Il presente lavoro illustra l’architettura, lo sviluppo e l’integrazione di “Rover Holly”, una piattaforma robotica autonoma basata su paradigma Edge AI. Attraverso l’impiego di una pipeline ibrida composta da algoritmi di visione artificiale (YOLOv8, marker ArUco) e un sistema di controllo firmware a basso livello con logiche di sicurezza VETO, il progetto documenta l’intero ciclo di vita del prodotto, dalla prototipazione meccanica alla validazione del software, offrendo un modello scalabile per l’innovazione tecnologica in ambito STEM.

## Indice

1. Struttura del Team e Metodologia Didattica
2. Architettura di Sistema e Pilastri di Comunicazione
3. Autonomous Ground Rover: Anatomia e Priorità
4. Architettura Embedded Multi-Thread e Protocolli di Navigazione
5. Determinismo Hardware: Firmware Arduino e Logica VETO
6. Configurazione di Sistema, Affidabilità e Cybersecurity
7. Elenco dei Materiali e Componenti (BOM)
8. Software Bill of Materials (SBOM)
9. Impatto Didattico
10. Conclusioni, Sviluppi Futuri e Strategia IP
11. Risorse e Repository Ufficiali

## Introduzione e Collocazione Didattica

Il presente documento costituisce la trattazione tecnica e la documentazione d’architettura del progetto “Dronebot 2026 — Team Holly”, un’unità di ricerca e sviluppo d’eccellenza del

Dipartimento di Informatica e Telecomunicazioni dell’ITC Vincenzo Arangio Ruiz di Roma. Il progetto si distingue per un’architettura coordinata Terra-Aria che combina robotica mobile e analisi video avanzata in tempo reale.

L’intero impianto metodologico è structured per fungere da modello didattico avanzato per gli studenti del triennio di specializzazione in Informatica. Il progetto si inserisce nelle linee guida della transizione digitale scolastica, unendo i paradigmi dell’Edge AI (Intelligenza Artificiale applicata sui dispositivi di frontiera), della computer vision in tempo reale e dei sistemi embedded distribuiti, basati su architetture eterogenee composte da Smartphone, Drone modificato, PC, Raspberry Pi 5 e Arduino Mega.

## 1. Struttura del Team e Metodologia Didattica (Co-Progettazione)

Il progetto è stato declinato come attività di alto apprendimento e co-progettazione orientata alle STEM, applicando la metodologia del Project Based Learning. In qualità di Technical Project Supervisor & Research Lead, ho delineato l’architettura dei sistemi e coordinato i flussi di lavoro degli studenti, concentrando l’attività di sviluppo personale sui moduli logici critici (Edge AI, sistemi concorrenti su Raspberry Pi 5 e firmware deterministico di Arduino).

L’organigramma ufficiale del progetto è così strutturato:

### 1.1 Leadership & Staff Docente

Prof. Riccardo Annolfi: Technical Project Supervisor & Research Lead (Ingegnerizzazione del software core del Rover, threading su Raspberry Pi 5, firmware ad anello chiuso su Arduino Mega, supervisione dell’integrazione di sistema).
Prof.ssa Giselda De Vita: Academic Coordinator & Project Coordinator.

### 1.2 Student Team (Sviluppo Moduli Operativi)

Raffaele Meo (Project Lead & Architect): Coordinamento software (Raspberry/PC), implementazione della visione artificiale (YOLO/OpenCV) e gestione flussi streaming RTMP.

Ibrahim Ouadjaout (Deployment & Telemetry): Supporto allo sviluppo del firmware di Arduino Mega, implementazione delle logiche base dei motori, condotta di volo del drone.
Davide D’Ubaldi (System Integration): Progettazione meccanica 3D del telaio e integrazione moduli hardware.
Gianmarco D’Angelis (Embedded Systems): Gestione del Power System, cablaggi di potenza e stabilità elettrica dei sensori.
Gabriel Priamo (Hardware Engineering): Monitoraggio dei flussi di telemetria e gestione del rilascio software.

## 2. Architettura di Sistema e Pilastri di Comunicazione

Il sistema si basa su una pipeline di comunicazione eterogenea strutturata a cascata su quattro livelli di rete e bus hardware, ottimizzati per la minima latenza e l’immunità ai guasti:

LIVELLO 1: SMARTPHONE (App DJI Fly + Drone) invia il flusso video alla Stazione di Terra sfruttando il protocollo RTMP (Live Streaming su rete Wi-Fi locale).
LIVELLO 2: STAZIONE PC DI TERRA elabora l’inferenza profonda YOLOv8 e il tracciamento dei marker ArUco, poi invia i comandi di coordinamento al Rover tramite chiamate asincrone HTTP POST (richieste REST /start e /stop sulla porta 5000).

LIVELLO 3: ROVER HOLLY (RASPBERRY PI 5) elabora le routine di Edge AI (codice holly_brain ), espone un flusso video MJPEG diagnostico per i test ambientali ed invia le stringhe di movimento (W, A, D) tramite accoppiamento seriale nativo UART, operando a valle di un adattamento dei livelli logici di tensione a 115200 baud verso la logica di attuazione.
LIVELLO 4: ROVER HOLLY (ARDUINO MEGA 2560) esegue il firmware di potenza a basso livello, campiona i sensori laser di prossimità sul bus I2C ed esercita la logica di blocco VETO in caso di collisione imminente.

### 2.1 La Catena dei Protocolli di Rete e di Bus

1. Streaming Video (Smartphone to PC via RTMP): Le immagini catturate in tempo reale dal drone vengono ricevute dall’applicazione di controllo DJI Fly installata sullo smartphone del pilota. Sfruttando la funzionalità di trasmissione live dell’applicazione, il flusso video viene convogliato alla stazione PC di terra tramite protocollo RTMP (Real-

Time Messaging Protocol), garantendo un campionamento video costante e a bassa latenza adatto all’elaborazione d’immagine.
2. Coordinamento di Flusso e Debug (PC to Rover via HTTP/Wi-Fi): Una volta che la stazione di terra ha elaborato l’immagine e validato l’evento target, l’invio dei comandi di attivazione e arresto verso l’unità mobile (Raspberry Pi 5) avviene sulla rete Wi-Fi locale tramite chiamate asincrone basate su architettura REST con protocollo HTTP (richieste POST /start e /stop ) destinate ad un micro-server Flask attivo a bordo del Rover. Lo

stesso server mette a disposizione degli operatori un endpoint di diagnostica per visualizzare direttamente dal browser lo streaming video della telecamera di bordo, consentendo test rapidi di calibrazione ottica direttamente sul campo.
3. Controllo Hardware (Raspberry Pi to Arduino via Seriale UART con Adattamento Logico): All’interno dell’architettura fisica del Rover, lo scambio di metriche cinematiche, telemetria dei sensori e comandi di marcia tra il computer di bordo (Raspberry Pi 5) e il microcontrollore core (Arduino Mega) è gestito tramite le linee seriali hardware native (bus UART) ad una velocità di transmissione asincrona di 115200 baud. Data la differente natura elettrica delle schede, in cui la Raspberry Pi 5 opera con logica transistore a 3.3V e l’Arduino Mega a 5V, l’accoppiamento dei pin RX/TX è eseguito interponendo un level shifter bidirezionale. Questa soluzione hardware garantisce la totale integrità dei segnali digitali, azzera i ritardi di propagazione e protegge i GPIO della Raspberry da sovratensioni distruttive.

## 3. Autonomous Ground Rover: Anatomia e Priorità

La piattaforma mobile terrestre “Holly” è strutturata su uno chassis a 4 livelli da 24cm x 13.5cm. Di seguito viene illustrata l’anatomia strutturale del Rover e la disposizione fisica dei suoi moduli di controllo, richiamati direttamente dalla repository.

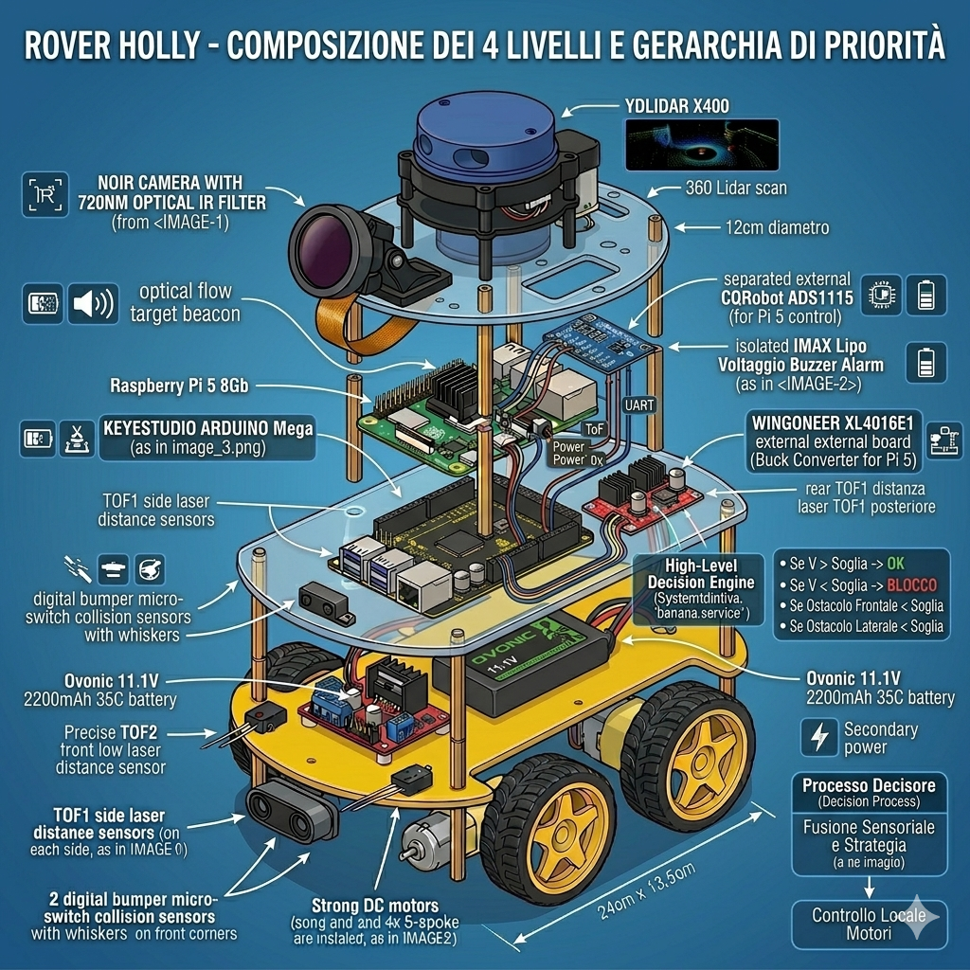
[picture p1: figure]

### 3.1 La Pipeline di Computer Vision ed Inferenza

Lato Stazione di Terra (Algoritmo di Visione e Deep Learning)

L’architettura software implementata nel loop principale riceve il flusso video in tempo reale convogliato dallo smartphone tramite il protocollo RTMP, intercettato localmente come sorgente video virtuale mediante le utility v4l2loopback e ffmpeg. L’elaborazione sfrutta un modello predittivo basato su tensori ad alta densità caricati su runtime PyTorch con accelerazione hardware CUDA.

Al fine di garantire la massima affidabilità ed escludere falsi positivi nello tracciamento dell’evento (e.g., variazioni repentine di luminosità o drift di hovering del drone), il sistema convalida il target spaziale solo se l’area della bounding box e lo shift cinematico rimangono stabili per un numero prefissato di frame consecutivi (streak pari a 7 frame).

Regola di Validazione Spaziale: Se l’Area della Bounding Box è maggiore o uguale a 5000 pixel E lo Spostamento del Centro del Target rispetto al frame precedente è inferiore a 100 pixel, il contatore incrementa. Raggiunti i 7 frame stabili, la stazione attiva il comando remoto.

Pseudocodice Logico della Pipeline Aerea (PC-side):

1. Inizializza VideoCapture sulla sorgente video virtuale del flusso RTMP.
2. Carica i pesi ottimizzati YOLOv8 (identificati dal file di configurazione best.pt ) ed

imposta la FASE = 1.
3. Configura il rilevatore ARUCODetector (dizionario DICT_4X4_50, ID target 10).
4. Ciclo continuo di scansione dei frame:
Se FASE uguale a 1: esegui l’inferenza profonda. Se l’area rilevata supera i 5000 pixel e lo spostamento spaziale è minore di 100 pixel incrementa lo streak. Al raggiungimento di 7 frame consecutivi invia la richiesta HTTP POST /start al server Flask della Raspberry Pi sulla porta 5000 e passa alla FASE = 2.
Se FASE uguale a 2 e il target circolare non è bloccato: esegui il tracciamento stazionario per 20 frame per calcolare il centro geometrico corretto.
Se FASE uguale a 2 e il target è agganciato: esegui la compensazione dinamica del movimento ed analizza la presenza del marker ArUco. Se gli angoli del marker sono interni al perimetro del cerchio per 5 frame consecutivi, invia la richiesta HTTP POST /stop alla Raspberry Pi per arrestare il Rover e interrompi l’esecuzione.
5. Rilascia le risorse di cattura video e chiudi la pipeline.

Lato Unità Mobile (Tracciamento Ottico di Frontiera)

L’inseguimento autonomo del drone da parte del Rover avviene tramite l’elaborazione a bassissima latenza operata dal thread vision_logic residente sul sistema operativo della Raspberry Pi 5.

Per eliminare l’interferenza delle sorgenti luminose ambientali nello spettro del visibile (luci artificiali, riflessi), la piattaforma adotta una combinazione hardware composta da una camera sprovvista di filtro IR (Pi Camera 3 NoIR Wide) e un filtro passa-alto ottico Hoya R72 (con soglia di taglio a 720 nm). Sotto la pancia del drone è collocato un LED a infrarossi (beacon attivo) ad alta intensità dotato di propria alimentazione e batteria indipendente, così da non intaccare l’autonomia di volo del velivolo. Il frame risultante isola perfettamente questo spot luminoso emesso dal LED infrarosso e viene elaborato tramite una pipeline di binarizzazione ed estrazione dei centroidi:

1. Acquisizione del frame in scala di grigi alla risoluzione di 640x480 pixel a 20 fotogrammi al secondo.
2. Applicazione della soglia di binarizzazione netta ( cv2.threshold impostata a valore

fisso 248) per isolare lo spot luminoso emesso dal LED infrarosso.
3. Esecuzione della routine di estrazione dei contorni ( cv2.findContours ) con annesso filtro geometrico sull’area per scartare i blob spuri di piccole dimensioni.
4. Calcolo dei momenti spaziali d’immagine ed estrazione della coordinata del centroide lungo l’asse X.
5. Logica di navigazione basata sulla posizione orizzontale del centroide:
Se la coordinata X si trova nella fascia centrale dello schermo (compresa tra 200 e 440 pixel), genera il comando seriale ‘W’ (Marcia Avanti Rettilinea).
Se la coordinata X è inferiore a 200 pixel, genera il comando seriale ‘A’ (Sterzata a Sinistra).
Se la coordinata X è superiore a 440 pixel, genera il comando seriale ‘D’ (Sterzata a Destra).
6. Trasmissione immediata della stringa di comando sul bus seriale UART.

## 4. Architettura Embedded Multi-Thread e Protocolli di Navigazione

### 4.1 Gestione Concorrente su Raspberry Pi 5

Per garantire determinismo operativo ed evitare il blocco del loop di controllo a causa dell’I/O asincrono delle periferiche hardware, lo script Python core ( holly_brain_v13.9.py ) implementa un’architettura a cinque thread daemon concorrenti. Questi thread alimentano costantemente le variabili globali di stato, che vengono campionate dal Main Loop a una frequenza fissa di 20 Hz:

listener : Gestisce la coda di ricezione della telemetria seriale asincrona proveniente da Arduino Mega ad una velocità di 115200 baud.
vision_logic : Gestisce l’acquisizione dei frame video via MJPEG, l’isolamento dei blob

infrarossi e il calcolo in tempo reale del vettore di tracking.

lidar_thread : Interfaccia il sensore YDLiDAR X4 Pro tramite porta seriale, mappando

una scansione laser bidimensionale a 360 gradi dello spazio circostante.
ads_thread : Monitora lo stato di carica energetica campionando il convertitore

analogico-digitale ADS1115 via bus I2C per prevenire crolli di tensione (Brown-out) e alimentare la telemetria a schermo.
run_flask : Espone gli endpoint REST dell’applicazione web, intercettando le chiamate HTTP asincrone provenienti dal computer aereo e gestendo la dashboard di controllo remoto. Include inoltre l’endpoint dedicato /video_feed per l’invio dello streaming

video nativo catturato dalla Pi Camera NoIR, consentendo agli operatori di monitorare in tempo reale l’inquadratura del Rover durante i test preliminari e le fasi di allineamento ottico.

### 4.2 Modello di Navigazione Stratificato e Controllo ad Anello Chiuso

La logica di movimento del Rover fonde i dati provenienti dai molteplici vettori sensoriali applicando una gerarchia rigida di sovrascrittura protetta (Safety Overrides), organizzata in 4 livelli logici per garantire la massima sicurezza del veicolo in movimento:

LIVELLO 3 (Massima Priorità): Recupero Urti Bumper -> Interviene in caso di scontro fisico rilevato dai due micro-switch meccanici anteriori provvisti di baffi (Bumper Destro e Bumper Sinistro), forzando una retromarcia asimmetrica di sicurezza gestita ad interrupt.
LIVELLO 2: Evitamento Ostacoli LiDAR -> Analisi dinamica ad ampio raggio del cono visivo frontale, mappato sull’arco angolare compreso tra 150 e 210 gradi (60 gradi totali di ampiezza) della scansione laser del LiDAR X4 Pro. Forza una deviazione immediata del veicolo indirizzandolo sui varchi d’uscita liberi disponibili, calcolati sopra la distanza minima di sicurezza di 350 mm.
LIVELLO 1: Correzioni Prossimità Matrice ToF -> Analisi spaziale a corto raggio tramite i 4 sensori a tempo di volo (VL53L0X / VL53L1X) disposti a croce sul perimetro (Frontale, Posteriore, Laterale Destro, Laterale Sinistro). Il sistema esegue micro-sterzate compensative o variazioni millimetriche della traiettoria in base al sensore stimolato: esegue un allontanamento rapido sul lato opposto se i ToF Laterali scendono sotto i 150 mm dalle pareti, rallenta proporzionalmente la marcia se il ToF Frontale rileva un avvicinamento progressivo, o inibisce le manovre di arretramento se il ToF Posteriore segnala un ingombro.
LIVELLO 0 (Marcia Nominale): Inseguimento Visione IR -> Livello base attivo in assenza di pericoli ambientali. Esegue il comando di marcia standard generato dall’algoritmo di inseguimento del centroide del LED IR (invio delle singole stringhe W, A, D).

### 4.3 Ingegnerizzazione del Power System e Cablaggi Hardware

Per garantire l’immunità dai disturbi elettromagnetici e prevenire cali di tensione (sag elettrici) indotti dagli spunti dei motori, l’architettura elettrica del Rover Holly implementa una rete a doppia alimentazione completamente isolata a livello di rami di corrente (Dual-Power System), fedelmente documentata nello schema di interconnessione ufficiale sotto riportato:

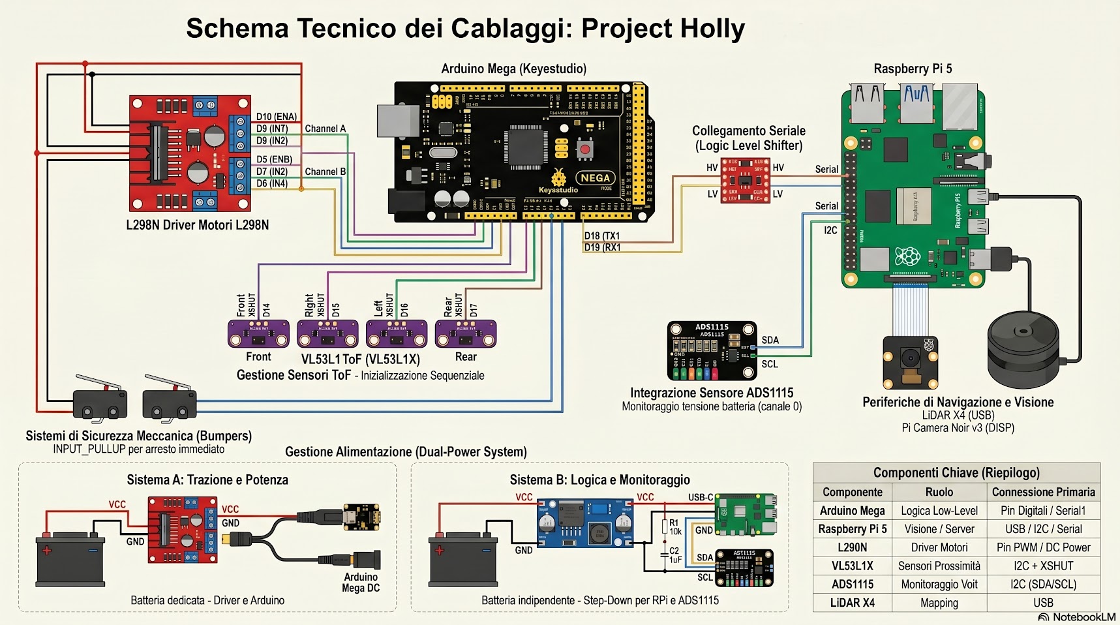
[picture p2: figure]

1. Ramo Logico di Bordo (Sottosistema AI, Visione & Server): Questo ramo fa capo a un pacco batteria LiPo dedicato a 2 celle (2S da 7.4V nominali, con fattore di scarica pari a 30C). Quando la batteria viene caricata al massimo del suo potenziale elettrochimico, la tensione di cella tocca i 4.1V - 4.2V, portando il valore complessivo erogato ai morsetti a circa 8.1V - 8.2V. La linea alimenta direttamente la Raspberry Pi 5, la Pi Camera NoIR dotata di illuminatore artificiale a infrarossi e il sensore LiDAR. La tensione è stabilizzata a valle tramite un modulo di regolazione DC-DC ad alta efficienza (Step-Down Buck Converter WINGONEER XL4016E1) per garantire un’erogazione continua a 5V/5A priva di fluttuazioni, sventando i reset del kernel o i blocchi del server Flask.
2. Ramo di Potenza e Attuazione (Motori & Sensori Locali): Gestito da una seconda batteria LiPo indipendente a 3 celle (3S da 11.1V nominali, 2200mAh 35C). Questa linea fornisce l’energia ad alta corrente necessaria direttamente ai driver del ponte H L298N per muovere i 4 motori in corrente continua e alimenta l’Arduino Mega 2560 (regolato sul jack DC) insieme alla matrice di sensori a corto raggio.

Sistemi Integrati di Monitoraggio Energetico e Telemetria:

Sicurezza Hardware Hard-Real-Time: Direttamente connesso al cavo del connettore di bilanciamento (Balance Plug) della batteria logica è presente un modulo tester/salvalipo hardware munito di allarme acustico a doppio buzzer. Il dispositivo esegue un campionamento diretto e, in caso di sbilanciamento o discesa di una singola cella sotto la soglia di sicurezza di 3.4V (corrispondente a 6.8V complessivi sotto carico), attiva immediatamente una segnalazione sonora ad alta intensità udibile sul campo, garantendo la protezione fisica dell’accumulatore ed evitando lo spegnimento improvviso del sistema operativo della Raspberry Pi.
Telemetria Software in Tempo Reale: In parallelo, per tracciare lo stato energetico direttamente sul monitor della dashboard di controllo, il Rover integra un modulo convertitore analogico-digitale ADS1115 interfacciato sul bus I2C (canale 0). Campionando costantemente i livelli di tensione delle batterie tramite il relativo thread concorrente Python ( ads_thread ), converte i segnali in metriche digitali inviandoli in tempo reale al monitor di telemetria. Se il software rileva un calo di tensione globale sotto i parametri nominali, avvia una procedura di protezione logica (High-Level Decision Engine impostato via systemd nativo) che inibisce i comandi di marcia avanti direttamente dal core Python.

## 5. Determinismo Hardware: Il Firmware Arduino e la Logica VETO

Mentre le computazioni algoritmiche ad alto livello (Computer Vision, processing del LiDAR) sono delegate al microprocessore Raspberry Pi, il controllo dei motori in corrente continua tramite ponte H L298N e la gestione della sicurezza a bassissima latenza sono demandati al firmware del microcontrollore Arduino Mega 2560 Keyestudio (identificato nel sorgente holly_mega_v12.11.ino ).

### 5.1 Risoluzione dei Conflitti di Indirizzamento sulla Matrice ToF (Bus I2C)

Il Rover impiega una matrice di 4 sensori di distanza laser a tempo di volo (VL53L0X / VL53L1X) per la mappatura perimetrale fissa. Poiché tali sensori condividono lo stesso indirizzo I2C hardware di fabbrica, il firmware implementa una procedura di inizializzazione sequenziale sfruttando i pin digitali di spegnimento (XSHUT, mappati sui pin D14, D15, D16, D17) cablati sul microcontrollore.

Ogni sensore viene mantenuto nello stato logico LOW (spento) e risvegliato singolarmente portando la rispettiva linea XSHUT allo stato HIGH; subito dopo il boot parziale, il firmware assegna via software un nuovo indirizzo univoco riconfigurando i registri interni prima di passare all’unità successiva. Questa tecnica consente la coesistenza dei 4 sensori della matrice sullo stesso bus di comunicazione a due fili (SDA/SCL).

### 5.2 La Funzione VETO Intermittente a Livello Firmware

Per escludere i ritardi o i freeze hardware intrinseci associati sullo stack di comunicazione seriale con la Raspberry Pi, Arduino esegue un controllo formale di sicurezza in tempo reale denominato Logica VETO.

Questa funzione analizza la telemetria locale dei sensori ToF e dei bumper meccanici a una frequenza di 25 Hz. In caso di violazione delle distanze di sicurezza minime frontali (distanza inferiore a 250 mm rilevata dal ToF Frontale) o di attivazione fisica dei micro-switch dei bumper (configurati in INPUT_PULLUP per l’arresto immediato), la funzione interviene

forzando lo spegnimento istantaneo dei driver di potenza dei motori, ignorando qualsiasi stringa di comando ricevuta via seriale dalla Raspberry Pi fino al ripristino delle condizioni operative di sicurezza.

Equazione di Stato della Sicurezza: La condizione di VETO si attiva se e solo se il comando richiesto è di marcia avanti (‘W’) E si verifica almeno una delle seguenti anomalie: distanza del ToF Frontale inferiore a 250mm, attivazione del bumper sinistro (stato LOW) o attivazione del bumper destro (stato LOW).

## 6. Configurazione di Sistema, Affidabilità e Cybersecurity

Per garantire la massima stabilità operativa sul campo ed eliminare totalmente il rischio di corruzione dei dati causato da disconnessioni improvvise o cali di tensione della sorgente di alimentazione principale, il sistema operativo dell’unità mobile (Raspberry Pi OS Lite 64-bit) è configurato in modalità immutabile.

### 6.1 Protezione del File System tramite OverlayFS

È stato configurato un livello logico di Overlay (OverlayFS) che intercetta tutte le chiamate di

scrittura dirette alla memoria flash della scheda SD, redirezionandole verso un’area volatile mappata interamente nella RAM di sistema. Al riavvio dell’hardware, il sistema operativo ritorna allo stato nativo validato e protetto, garantendo la totale immunità del kernel da blocchi software dovuti a spegnimenti repentini.

Modalità Gara (Sola Lettura): Configurabile stabilmente tramite l’utility integrata raspi-config (Performance Options -> Overlay File System -> Enable), preceduta da una direttiva kernel di sincronizzazione dei blocchi di memoria ( sync ).

Modalità Sviluppo (Lettura/Scrittura): Accessibile per modifiche estemporanee alle routine o patch del codice core tramite forzatura manuale a riga di comando eseguendo l’istruzione di remount in modalità “rw” sulla directory /boot/firmware .

### 6.2 Automazione dei Processi via Demone Systemd

L’esecuzione del codice Edge AI è interamente automatizzata e gestita come un servizio nativo di background del sistema operativo tramite Systemd. Il demone monitora costantemente lo stato del processo e ne garantisce il riavvio istantaneo in caso di eccezioni software impreviste o di momentaneo crash della linea seriale.

Il file di configurazione holly_rover.service è depositato nella directory /etc/systemd/system/ , include la direttiva Restart=always per garantire la resilienza del software e imposta come vincolo di esecuzione il caricamento completo dello stack di rete ( After=network.target ), agganciando l’attivazione del processo al boot multiboot del

sistema operativo.

## 7. Elenco dei Materiali e Componenti (Bill of Materials)

La distinta dei componenti hardware necessari per la replica integrale della piattaforma mobile “Rover Holly” è strutturata nella seguente tabella analitica dei costi complessivi di sviluppo:

# | Product | Description

Unit
Price

Qty

Row
Total
1 | Raspberry Pi 5 | Raspberry Pi 5 — 8 GB RAM | €
| | | 136,00 | 1 | €
| | | | | 136,00
2 | Scheda SD | Micro SD Card HC 64 GB | € 14,00 | 1 | € 14,00

# | Product | Description

Unit
Price

Qty

Row
Total
| | Class 10 + Adapter
3 | Case Raspberry Pi 5

Miuzei Aluminium Case
for Raspberry Pi 5
€ 18,99 | 1 | € 18,99

4

Alimentatore ufficiale
Raspberry Pi 5

Official Raspberry Pi 5
USB-C 27 W Power
Supply
€ 18,21 | 1 | € 18,21

5

Raspberry Pi Camera
Module 3 NoIR Wide

Raspberry Pi Camera
Module 3 NoIR Wide
€ 48,40 | 1 | € 48,40
6 | YDLiDAR X4 Pro

360° 2D Laser Range
LiDAR Sensor
€ 75,00 | 1 | € 75,00

7

Hoya Infrared Filter
R72 Ø55 mm

Hoya IR Filter R72 Ø55
mm — 720 nm
€ 45,00 | 1 | € 45,00
8 | LED IR 5 mm 210 mW

PopEsq® IR LED 5 mm
210 mW
€ 1,50 | 1 | € 1,50

9

Cavi a nastro
fotocamera

Ribbon Cables
Compatible with
Raspberry Pi 5
€ 3,00 | 1 | € 3,00
10 | Batteria LiPo 7.4 V

Xell-Sport 7.4 V 2700
mAh 2S 30C LiPo Battery
€ 23,60 | 1 | € 23,60
11 | Chassis 4 livelli | 4-Level Robot Chassis | € 15,00 | 1 | € 15,00

12

Connettori, cavetti e
guaine

Deans T-Connectors, JST,
Cables & Sleeves
€ 5,00 | 1 | € 5,00
13 | Motor Driver L298N

L298N Dual H-Bridge
Motor Driver Module
€ 7,00 | 1 | € 7,00

14

4× Motori 12 V con
ruote

4× 12 V DC Motors with
Wheels
| | | € 12,00 | 1 | € 12,00
15 | Batteria LiPo 11.1 V | Xell-Light 11.1 V 1300 | € 16,90 | 1 | € 16,90

# | Product | Description

Unit
Price

Qty

Row
Total
| | mAh 3S 20C LiPo Battery

16

Step-Down Buck
Converter XL4016E1

DC 4–40 V → 1.25–36 V,
8 A Voltage Regulator
€ 9,99 | 1 | € 9,99

17

ADS1115 16-bit ADC
Module

CQRobot ADS1115 16-
Bit ADC Conversion
Module
€ 24,99 | 1 | € 24,99

18

LiPo Voltage Tester /
Buzzer Alarm

1–8S LiPo Battery
Voltage Tester with
Buzzer
€ 3,00 | 1 | € 3,00

Spesa Totale di Progetto: € 477,58

## 8. Software Bill of Materials (SBOM)

Ecosistema software, librerie di runtime e dipendenze strutturate divise per nodi di rete del sistema accoppiato:

### 8.1 Nodo di Rete PC — Stazione di Rilevamento e Inferenza

Ambiente virtuale gestito con Pixi (canali conda-forge + pip). File di riferimento: pc/pixi.toml .

Pacchetto | Versione | Uso
Python | 3.12.x | Linguaggio base d’inferenza
ultralytics | >= 8.0.0 | YOLOv8 — rilevamento e classificazione target aereo
opencv | >= 4.10.0

Acquisizione video, rilevamento ArUco, rendering dell’interfaccia

Pacchetto | Versione | Uso
pytorch | >= 2.0.0 | Backend inferenza neurale (+ accelerazione hardware CUDA 12.1)
torchvision | >= 0.15.0 | Trasformazioni tensoriali delle immagini per YOLOv8
numpy | >= 1.24

Calcoli geometrici (centri di massa, cerchio di fuoco, distanze)

requests | (via pip) | Gestione chiamate HTTP POST verso il server Flask del rover
rich | >= 13.0.0 | Formattazione avanzata dell’output via console di log
python- dotenv | >= 1.0.0 | Caricamento e isolamento delle variabili d’ambiente

v4l2loopback

kernel
module

Istanziazione webcam virtuale su /dev/video10

scrcpy | sistema (apt)

Mirroring dello streaming dello schermo dello smartphone Android

ffmpeg | sistema | Ingestione stream RTMP nativo trasmesso dall’App DJI Fly
adb | sistema | Gestione connessione via Android Debug Bridge

### 8.2 Nodo Mobile — Raspberry Pi 5 (Edge AI)

Ambiente logico basato su Python venv all’interno di Raspberry Pi OS Lite 64-bit.

Dipendenze di Sistema (apt)

python3-pip : Installazione e manutenzione dei moduli.
i2c-tools : Utility di scansione e debug del bus hardware ( i2cdetect ). git : Controllo di versione del software distribuito.
libcamera-dev : Dipendenze e astrazioni hardware per la fotocamera.

Librerie Python Core (pip / virtual environment)

Pacchetto | Versione | Uso
Python | 3.11+ | Linguaggio base dell’unità mobile
Flask | >= 2.x

Gestione API REST ( /start , /stop , /telemetria ) e

| | dashboard web
pyserial | >= 3.x | Gestione del flusso asincrono UART con Arduino Mega
opencv- headless | >= 4.x | Visione a basso overhead (filtri passa-alto, thresholding, contorni)
numpy | >= 1.24

Vettorizzazione ed elaborazione array del LiDAR (ricerca varchi)

ydlidar

Python
SDK

Interfaccia nativa a basso livello per YDLiDAR X4 Pro su /dev/ttyUSB0

adafruit-ads1x15

>= 2.x

Driver di astrazione per chip ADS1115 16-bit ADC via bus I2C

adafruit-blinka >= 8.x

Hardware Abstraction Layer (HAL) Adafruit per GPIO Raspberry Pi

Tool di Sistema

rpicam-vid : Acquisizione in tempo reale del flusso video MJPEG dalla fotocamera Pi Camera 3 NoIR Wide.
systemd : Gestione demone per l’avvio automatico delle routine e monitoraggio al boot ( holly_rover.service ).

### 8.3 Firmware Microcontrollore — Arduino Mega Keyestudio

Ambiente compilato tramite Arduino IDE v2.x ( rover/arduino/holly_mega_v12.11.ino ).

Libreria | Versione | Autore | Uso
Wire | built-in | Arduino | Gestione bus I2C hardware (comunicazione sincrona)
VL53L0X | >= 1.3.x | Pololu

Driver e registri sensori Time-of-Flight (distanze reali in mm)

## 9. Impatto Didattico

L’ingegnerizzazione dell’architettura integrata “Rover Holly” dimostra come l’unione di tecnologie open-source altamente eterogenee (streaming RTMP, linguaggio Python, librerie OpenCV, framework PyTorch, programmazione C++ embedded) permetta di declinare concetti complessi e astratti di Intelligenza Artificiale applicata e Robotica in scenari reali, stimolanti e tangibili per gli studenti.

I sorgenti completi, i diagrammi di cablaggio e le distinte dei materiali (BOM/SBOM) allegate costituiscono un ecosistema di contenuti digitali pienamente riutilizzabili e scalabili, configurandosi come un’eccellenza assoluta nell’ambito dell’insegnamento delle discipline STEM e della transizione verso l’innovazione tecnologica d’istituto.

## 10. Conclusioni, Sviluppi Futuri e Strategia IP

Il Rover Holly ha dimostrato la robustezza del proprio framework di navigazione, confermando la validità delle scelte architetturali adottate. Il sistema, grazie alla modularità dei componenti, permette una manutenzione semplificata e una rapida implementazione di nuove funzionalità.

Roadmap di Sviluppo e Strategia di Proprietà Intellettuale

Data la natura innovativa delle soluzioni architetturali adottate — in particolare per quanto concerne le metodologie di sincronizzazione ottica tra unità mobili e le logiche di commutazione ridondante anti-jamming — il team ha avviato una fase di analisi preliminare volta a identificare gli elementi di “attività inventiva” del sistema.

Nell’ottica di una crescita progettuale che superi l’ambito puramente didattico, sono stati definiti i seguenti indirizzi strategici:

Consolidamento Tecnico: Priorità assoluta è il completamento dei test di stress per la conferma della robustezza algoritmica, condizione imprescindibile per qualsiasi evoluzione industriale.
Gestione della Proprietà Intellettuale (IP): Una volta raggiunta la stabilità operativa, il team procederà a una valutazione formale delle componenti core del software e dell’architettura hardware di controllo. Tali componenti verranno valutate come candidate per il deposito di privative industriali, al fine di proteggere il know-how proprietario sviluppato internamente.
Trasparenza e Ricerca: In linea con lo spirito del progetto, i risultati sperimentali (sia i successi che le criticità incontrate durante la fase di R&D) continueranno a essere documentati per scopi didattici, mantenendo tuttavia riservate le specifiche tecniche dei moduli logici definiti “critici” per il vantaggio competitivo del sistema.

Prospettive Tecnologiche

Le direttrici di ricerca si concentreranno sull’integrazione di sistemi di SLAM (Simultaneous Localization and Mapping) per una navigazione in ambienti non mappati e sull’ottimizzazione del Power Management. Tali implementazioni sono previste per la sessione autunnale di test, finalizzata alla partecipazione a contesti di innovazione robotica nazionale ed europea.

## 11. Risorse e Repository Ufficiali

Repository GitHub Ufficiali: dronebot-2026 (https://github.com/ITC-V-A-Ruiz-Dip-di-Inf-e-Telecom/dronebot-2026)
Pagina Istituzionale del Team: Team Holly - Advanced Robotics (https://itc-v-a-ruiz-dip-di-inf-e-telecom.github.io/dronebot-2026/team-holly/) Modelli d’Involucro 3D (Camera Buia & Supporti): 3D Models Directory (https://github.com/ITC-V-A-Ruiz-Dip-di-Inf-e-Telecom/dronebot-2026/tree/main/3dModels) Archivio Media e Immagini di Test: Project Media Branch (https://github.com/ITC-V-A-Ruiz-Dip-di-Inf-e-Telecom/dronebot-2026/tree/main/media)

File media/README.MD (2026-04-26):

# 📸 Test Screenshots Gallery

| Test Session 1 | Test Session 2 |
| :---: | :---: |
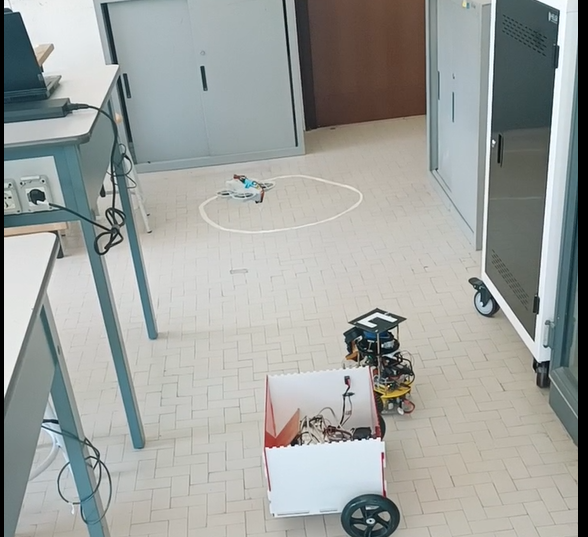
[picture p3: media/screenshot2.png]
|  |  |
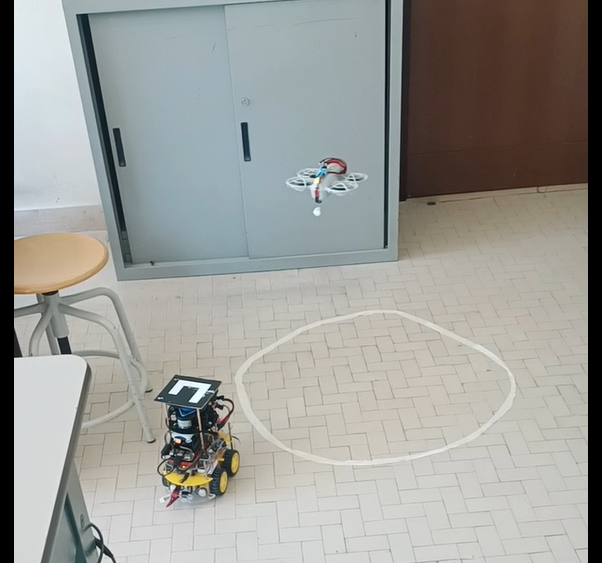
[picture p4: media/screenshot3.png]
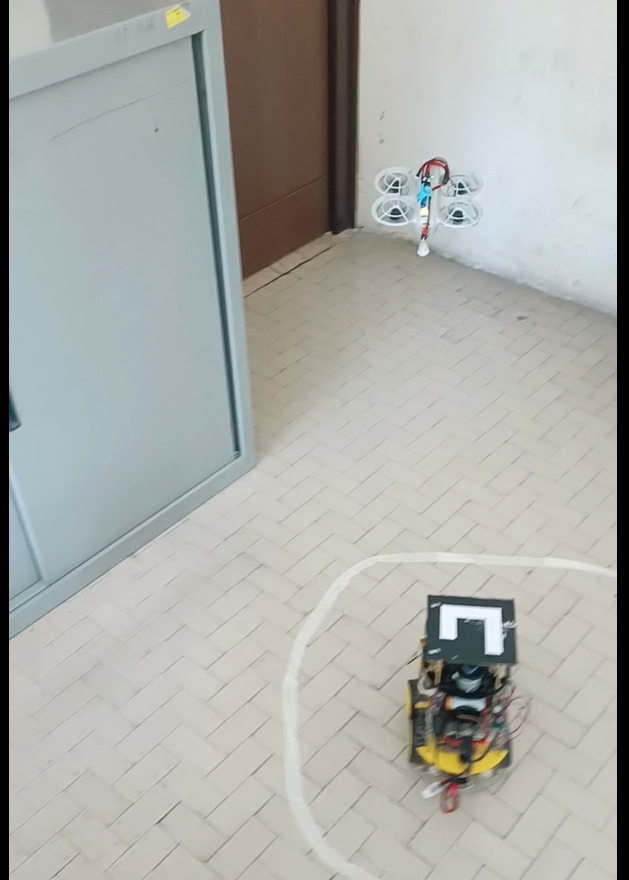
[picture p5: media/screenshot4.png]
|  |  |
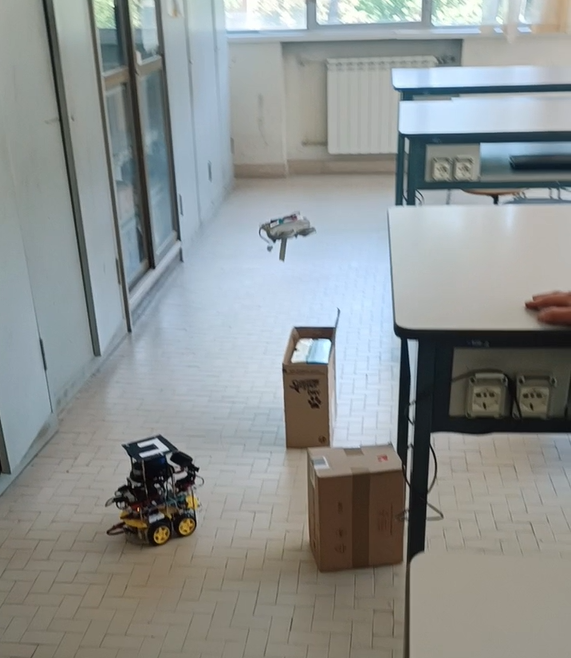
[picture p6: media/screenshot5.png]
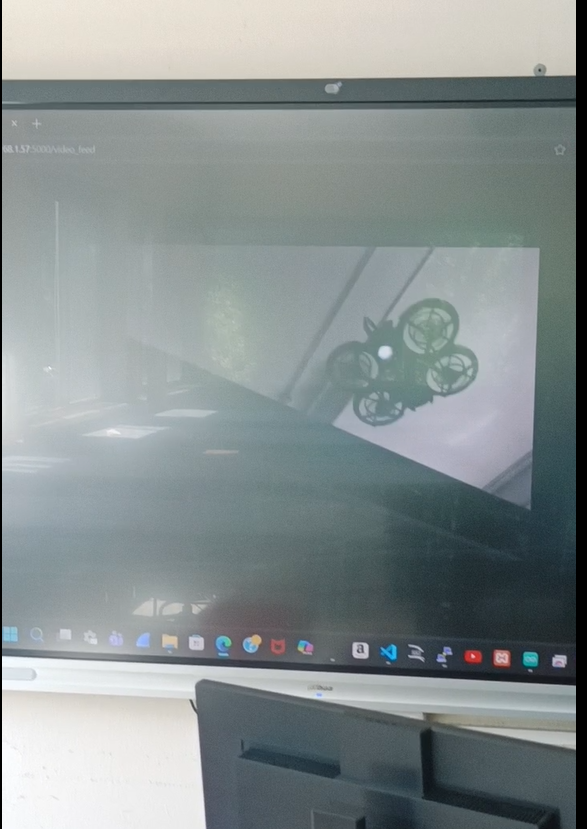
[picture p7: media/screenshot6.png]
|  |  |
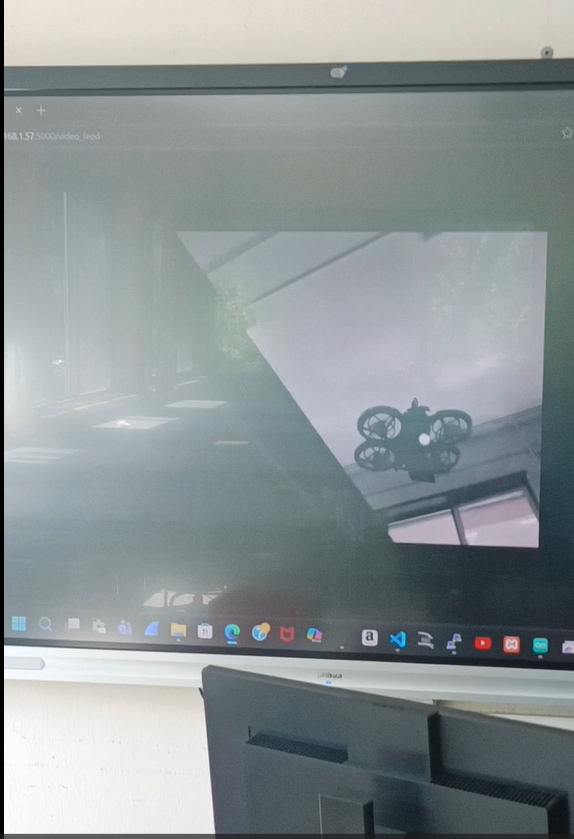
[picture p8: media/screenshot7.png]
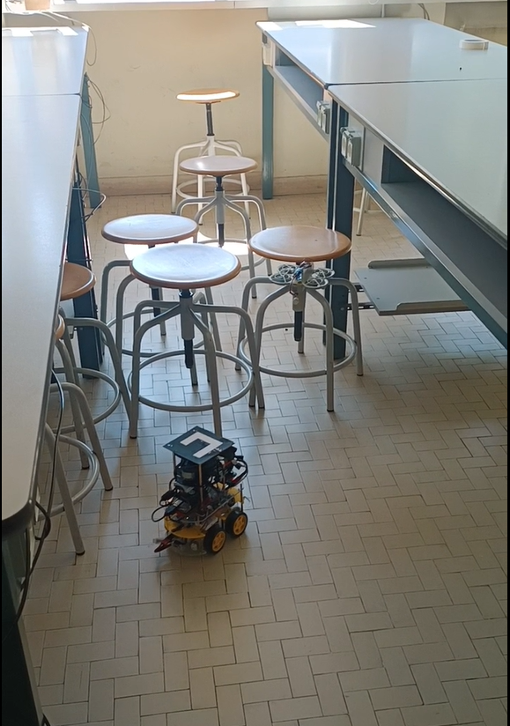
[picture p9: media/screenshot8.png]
|  |  |
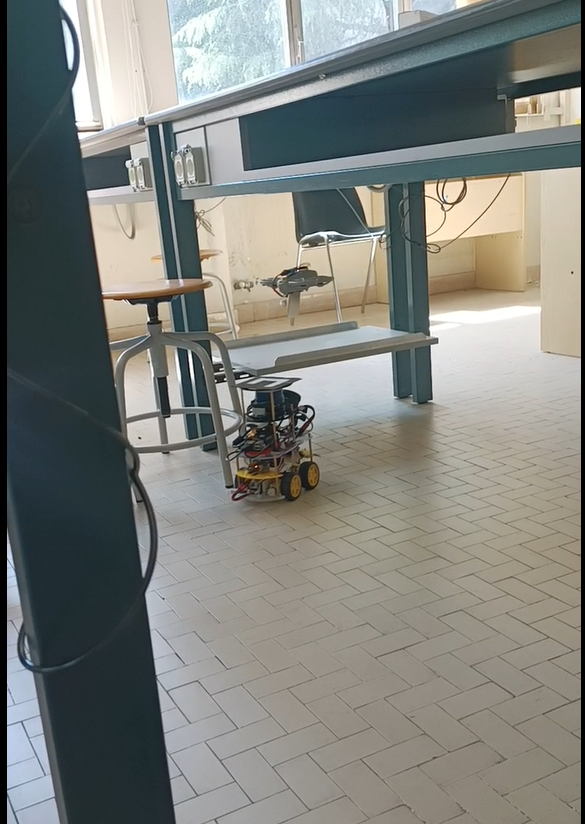
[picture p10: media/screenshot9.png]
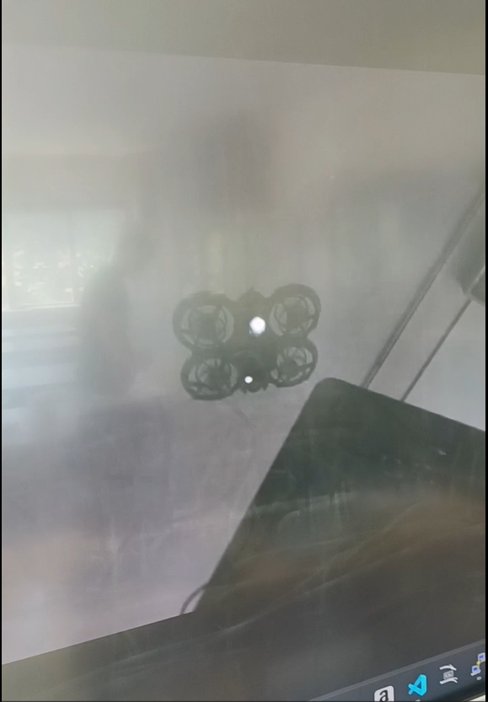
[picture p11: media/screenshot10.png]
|  |  |
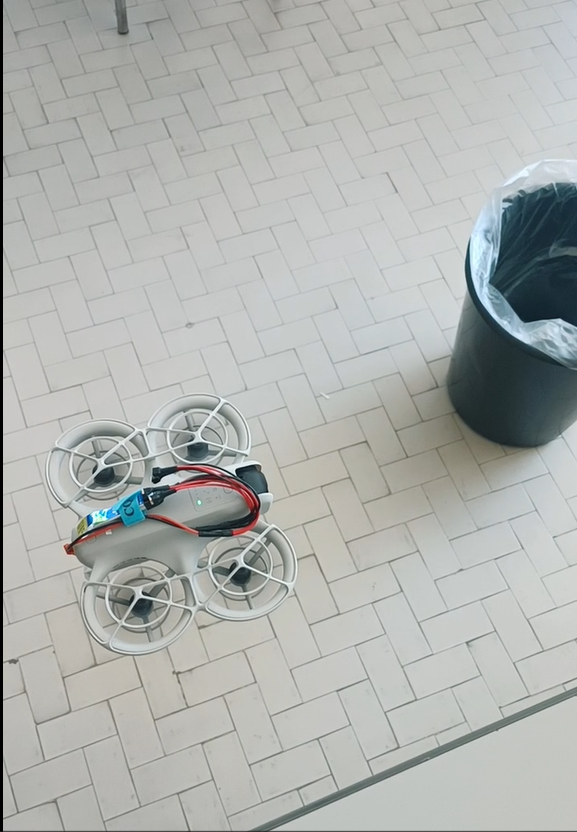
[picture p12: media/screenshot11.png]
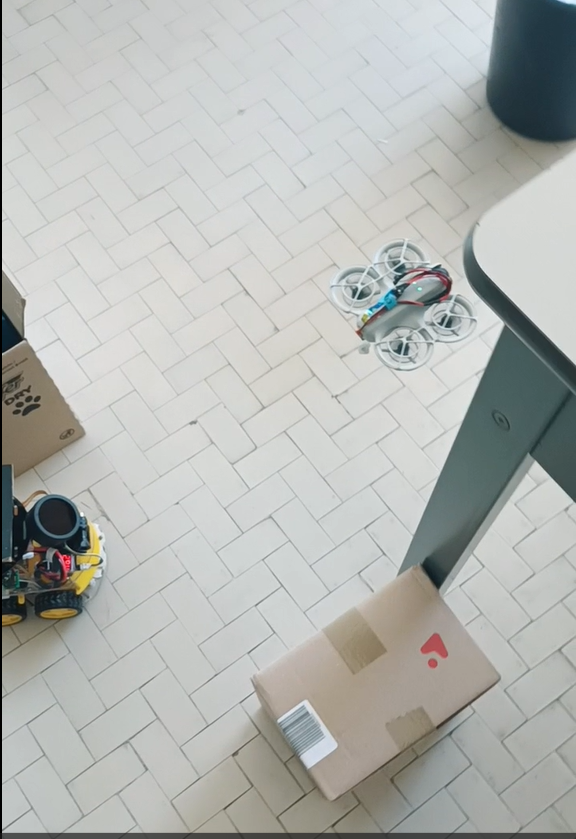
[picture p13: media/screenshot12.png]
|  |  |
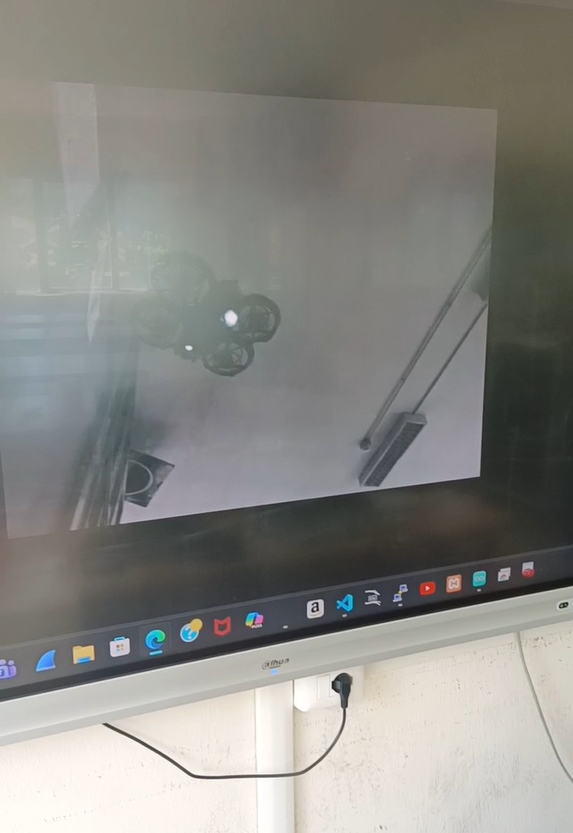
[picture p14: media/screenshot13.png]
|  |

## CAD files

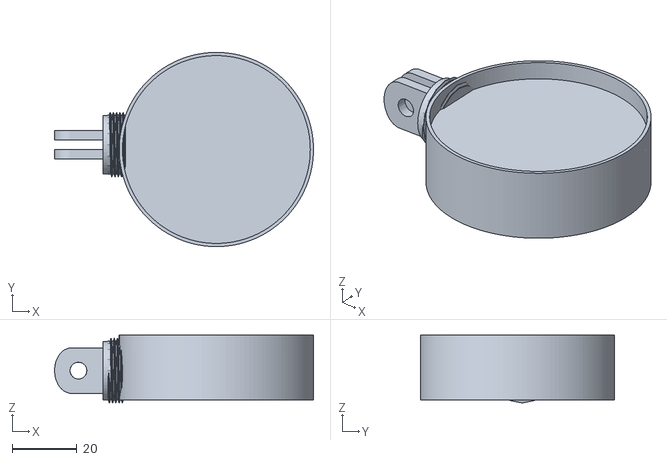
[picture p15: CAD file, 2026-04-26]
3dModels/supporto.stl
80.0 x 60.0 x 21.0

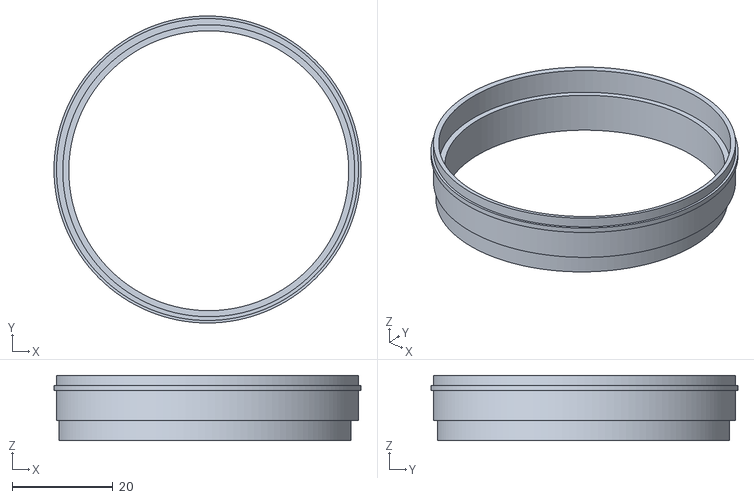
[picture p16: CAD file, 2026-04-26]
3dModels/estensione.stl
61.0 x 61.0 x 13.0

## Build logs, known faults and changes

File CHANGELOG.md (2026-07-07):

# Changelog — DroneBot 2026

Il progetto segue un'evoluzione per versioni successive. Ogni versione rilevante sarà taggata e, quando utile, pubblicata come Release.

## [4.0] — 2026-04-26

### Added
- Sistema di logging strutturato per gli script PC (`pc/logging.toml`, `pc/src/utils/log_setup.py`)
- SBOM (Software Bill of Materials) del progetto (`SBOM.md`)
- Bill of Materials hardware del rover (`BILL_OF_MATERIALS.md`)
- Diagramma tecnico dell'architettura hardware (`Technical_Diagram.jpg`)
- Script di setup separato per ffmpeg RTMP (`pc/setup_ffmpeg_rtmp.sh`)
- Workflow GitHub Actions per release automatica al push di tag `v*` (`.github/workflows/release.yml`)
- File `Team.md` con composizione del team
- README completo con flowchart di missione, istruzioni di setup e schema elettrico
- Modelli 3D per camera oscura e supporto GoPro (`3dModels/estensione.stl`, `3dModels/supporto.stl`)
- README nella cartella `media/` per preview immagini su GitHub

### Changed
- Refactoring script PC: `flask_client.py`, `controller.py`, `main.py` e `yolo_detector.py` aggiornati con logging integrato
- Aggiornati endpoint Flask e valori di configurazione in `pc/src/config.py`
- Rinominato `setup.sh` → `setup_pytorch.sh` per maggiore chiarezza
- Rinominate immagini nella cartella `media/` con nomi leggibili (`screenshot2.png` … `screenshot13.png`)
- README aggiornato: aggiunta fase 2 con sottofasi, migliorata leggibilità dei flowchart, corrette indicazioni hardware (pin seriali Arduino 18/19, step-down batteria Raspberry)
- Dipendenze PC aggiornate (`pc/pixi.toml`, `pc/pixi.lock`)

### Removed
- Rimossa directory `docs/` (contenuto migrato in README e Team.md)

## [3.0] — 2026-04-22

### Added
- Integrazione completa di 4 sensori ToF VL53L0X (frontale, posteriore, sinistro, destro)
- Aggiunta sensori bumper (baffi) per rilevamento collisioni fisiche
- Logica di sicurezza omnidirezionale con veto su tutti e 4 i movimenti
- Correzione sterzata in retromarcia tramite baffi (comandi Q/E)
- Versione finale software Raspberry Pi con comunicazione seriale completa
- Segnale di fase per coordinazione missione con server Flask
- Workflow GitHub Actions per release automatica al push di tag v*

## [2.0] — 2026-04-13

### Added
- Integrazione sensore ToF VL53L0X frontale per rilevamento ostacoli
- Sistema di telemetria: trasmissione distanza frontale al Raspberry Pi in tempo reale
- Dashboard di controllo aggiornata con indicatore distanza
- Logica di sicurezza (veto): blocco automatico avanzamento se ostacolo < 20 cm
- Script PC per rilevamento fuoco tramite YOLO e marker ArUco

### Fixed
- Gestione errori apertura porta seriale nel software Raspberry Pi

## [1.0] — 2026-03-23

### Added
- Prima versione firmware Arduino Mega per controllo motori tramite driver L298N
- Ricezione comandi di movimento (W/A/S/D/X) via porta seriale dal Raspberry Pi
- Prima versione software controllo Raspberry Pi con server web Flask
- Interfaccia HTML con bottoni per invio comandi di movimento al rover

## [0.0] — Creazione account Organization e Setup repository
- Creata repository e struttura cartelle iniziale.
- Aggiunti README, changelog e decision log.
- Definite regole d'oro per alimentazione e affidabilità.

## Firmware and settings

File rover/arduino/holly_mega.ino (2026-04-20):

#include <Wire.h>
#include <VL53L0X.h>

#define ENA 10 
#define IN1 9
#define IN2 8
#define IN3 7
#define IN4 6
#define ENB 5
#define X_F 14 
#define X_R 15 
#define X_L 16 
#define X_B 17 
#define B_SX 52 
#define B_DX 53 

int vel = 80; 
char comando_rpi = 'X'; 
VL53L0X sF, sR, sL, sB;

void setup() {
  Serial1.begin(115200); 
  Wire.begin();
  pinMode(B_SX, INPUT_PULLUP); pinMode(B_DX, INPUT_PULLUP);
  pinMode(ENA, OUTPUT); pinMode(IN1, OUTPUT); pinMode(IN2, OUTPUT);
  pinMode(ENB, OUTPUT); pinMode(IN3, OUTPUT); pinMode(IN4, OUTPUT);

  pinMode(X_F, OUTPUT); pinMode(X_R, OUTPUT); pinMode(X_L, OUTPUT); pinMode(X_B, OUTPUT);
  digitalWrite(X_F, LOW); digitalWrite(X_R, LOW); digitalWrite(X_L, LOW); digitalWrite(X_B, LOW);
  delay(100);
  initTof(sF, X_F, 0x30); initTof(sR, X_R, 0x31); initTof(sL, X_L, 0x32); initTof(sB, X_B, 0x33);
}

void initTof(VL53L0X &s, int p, uint8_t a) {
  digitalWrite(p, HIGH); delay(50);
  if(s.init()){ s.setAddress(a); s.setTimeout(200); s.startContinuous(); }
}

void loop() {
  int dF = sF.readRangeContinuousMillimeters();
  int dL = sL.readRangeContinuousMillimeters();
  int dR = sR.readRangeContinuousMillimeters();
  int dB = sB.readRangeContinuousMillimeters();
  bool bSX = (digitalRead(B_SX) == LOW);
  bool bDX = (digitalRead(B_DX) == LOW);

if (Serial1.available() > 0) { comando_rpi = Serial1.read(); }

  char azione = comando_rpi;

  // VETO DI SICUREZZA (Omnidirezionale)
  if (comando_rpi == 'W' && ((dF < 250 && dF > 0) || bSX || bDX)) azione = 'X';
  if (comando_rpi == 'S' && (dB < 200 && dB > 0)) azione = 'X';
  
  // Laterali meno sensibili per permettere manovre in spazi stretti
  if (comando_rpi == 'A' && (dL < 120 && dL > 0)) azione = 'X';
  if (comando_rpi == 'D' && (dR < 120 && dR > 0)) azione = 'X';

  esegui(azione);

  // Telemetria per Raspberry
  Serial1.print("DATA:"); Serial1.print(dF); Serial1.print(",");
  Serial1.print(dL); Serial1.print(","); Serial1.print(dR); Serial1.print(",");
  Serial1.print(dB); Serial1.print(","); Serial1.print(bSX); Serial1.print(",");
  Serial1.println(bDX);

  delay(40); 
}

void esegui(char c) {
  if (c == 'W') muovi(vel, vel);
  else if (c == 'S') muovi(-vel, -vel);
  else if (c == 'A') muovi(-vel, vel);
  else if (c == 'D') muovi(vel, -vel);
  // CORREZIONE STERZATA IN RETRO
  else if (c == 'Q') muovi(-vel/2, -vel); // Baffo SX colpito: Culo a SX, Muso a DX
  else if (c == 'E') muovi(-vel, -vel/2); // Baffo DX colpito: Culo a DX, Muso a SX
  else stoppa();
}

void muovi(int l, int r) {
  digitalWrite(IN1, l > 0 ? LOW : HIGH); digitalWrite(IN2, l > 0 ? HIGH : LOW);
  analogWrite(ENA, abs(l));
  digitalWrite(IN3, r > 0 ? LOW : HIGH); digitalWrite(IN4, r > 0 ? HIGH : LOW);
  analogWrite(ENB, abs(r));
}

void stoppa() {
  digitalWrite(IN1, LOW); digitalWrite(IN2, LOW);
  digitalWrite(IN3, LOW); digitalWrite(IN4, LOW);
  analogWrite(ENA, 0); analogWrite(ENB, 0);
}

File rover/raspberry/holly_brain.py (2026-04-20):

import serial, threading, time, sys, cv2, numpy as np, subprocess, shlex, os, ydlidar
from flask import Flask, request, jsonify, Response, render_template_string
import board, busio
import adafruit_ads1x15.ads1115 as ADS
from adafruit_ads1x15.analog_in import AnalogIn

# --- CONFIGURAZIONE FLASK ---
app = Flask(__name__)
os.system("sudo pkill rpicam-vid > /dev/null 2>&1")

# --- STATI E VARIABILI GLOBALI ---
running = True
stato_gara = "ATTESA"
comando_led = "X"
punti_lidar = [5000] * 360
tof_f, tof_l, tof_r, tof_b = 0, 0, 0, 0
b_sx, b_dx = 0, 0
v_batteria_totale = 0.0
v_su_a0 = 0.0
ser = serial.Serial('/dev/serial0', 115200, timeout=0.05)
ultimo_frame_jpg = None
frame_lock = threading.Lock()

# --- INTERFACCIA HTML (Identica alla 13.5) ---
HTML_PAGE = """
<!DOCTYPE html>
<html>
<head>
    <title>Holly Control Center</title>
    <meta name="viewport" content="width=device-width, initial-scale=1">
    <style>
        body { font-family: sans-serif; text-align: center; background: #1a1a1a; color: white; padding: 10px; }
        .btn { padding: 20px 40px; font-size: 20px; margin: 10px; cursor: pointer; border: none; border-radius: 8px; font-weight: bold; }
        .start { background: #28a745; color: white; }
        .stop { background: #dc3545; color: white; }
        #video { width: 100%; max-width: 640px; border: 3px solid #444; border-radius: 10px; }
        .status-bar { background: #333; padding: 15px; margin-bottom: 20px; font-size: 1.2em; border-radius: 5px; }
        .val { color: #ffc107; font-weight: bold; }
    </style>
</head>
<body>
    <div class="status-bar">
        STATO: <span id="stato_txt" class="val">ATTESA</span> |
        BATT TOTALE: <span id="batt_txt" class="val">0.0V</span>
    </div>
    <button class="btn start" onclick="manda('start')">START RACE</button>
    <button class="btn stop" onclick="manda('stop')">EMERGENCY STOP</button>
    <br><br>
    <img id="video" src="/video_feed">
    <script>
        function manda(azione) {
            fetch('/' + azione, { method: 'POST' })
            .then(r => r.json())
            .then(d => document.getElementById('stato_txt').innerText = d.message.toUpperCase());
        }
        setInterval(() => {
            fetch('/telemetria').then(r => r.json()).then(d => {
                document.getElementById('batt_txt').innerText = d.batt_tot;
                document.getElementById('stato_txt').innerText = d.stato;
            });
        }, 2000);
    </script>
</body>
</html>
"""

@app.route('/')
def index(): return render_template_string(HTML_PAGE)

@app.route('/start', methods=['POST'])
def start_gara():
    global stato_gara
    stato_gara = "IN_MARCIA"
    return jsonify({"status": "ok", "message": "IN_MARCIA"})

@app.route('/stop', methods=['POST'])
def stop_gara():
    global stato_gara
    stato_gara = "ATTESA"
    return jsonify({"status": "ok", "message": "ATTESA"})

@app.route('/telemetria', methods=['GET'])
def get_telemetria():
    return jsonify({
        "stato": stato_gara,
        "v_a0": f"{v_su_a0:.3f}V",
        "batt_tot": f"{v_batteria_totale:.2f}V",
        "tof": {"F": tof_f, "L": tof_l, "R": tof_r, "B": tof_b},
        "bump": {"SX": b_sx, "DX": b_dx},
        "cmd": comando_led
    })

def gen_frames():
    global ultimo_frame_jpg
    while running:
        with frame_lock:
            if ultimo_frame_jpg is None: continue
            frame = ultimo_frame_jpg
        yield (b'--frame\r\n' b'Content-Type: image/jpeg\r\n\r\n' + frame + b'\r\n')
        time.sleep(0.05)

@app.route('/video_feed')
def video_feed():
    return Response(gen_frames(), mimetype='multipart/x-mixed-replace; boundary=frame')

def ads_thread():
    global v_batteria_totale, v_su_a0, running
    try:
        i2c = busio.I2C(board.SCL, board.SDA); ads = ADS.ADS1115(i2c); chan = AnalogIn(ads, 0)
        while running:
            v_su_a0 = chan.voltage
            v_batteria_totale = v_su_a0 * 3.082
            time.sleep(1.0)
    except Exception as e: print(f"\n[ERRORE ADS]: {e}")

def listener():
    global tof_f, tof_l, tof_r, tof_b, b_sx, b_dx, running
    while running:
        if ser.in_waiting > 0:
            try:
                line = ser.readline().decode('utf-8', errors='ignore').strip()
                if "DATA:" in line:
                    p = line.replace("DATA:", "").split(",")
                    if len(p) >= 6:
                        tof_f, tof_l, tof_r, tof_b = int(p[0]), int(p[1]), int(p[2]), int(p[3])
                        b_sx, b_dx = int(p[4]), int(p[5])
            except: pass
        time.sleep(0.01)

def lidar_thread():
    global punti_lidar, running
    laser = ydlidar.CYdLidar()
    laser.setlidaropt(ydlidar.LidarPropSerialPort, "/dev/ttyUSB0")
    laser.setlidaropt(ydlidar.LidarPropSerialBaudrate, 128000)
    if laser.initialize() and laser.turnOn():
        scan = ydlidar.LaserScan()
        while running:
            if laser.doProcessSimple(scan):
                for p in scan.points:
                    ang = int(np.degrees(p.angle)) % 360
                    punti_lidar[ang] = p.range * 1000
            time.sleep(0.05)

def vision_logic():
    global comando_led, ultimo_frame_jpg, running
    cmd_video = "rpicam-vid -t 0 --shutter 2000 --gain 1 --width 640 --height 480 -n --codec mjpeg -o -"
    proc = subprocess.Popen(shlex.split(cmd_video), stdout=subprocess.PIPE, stderr=subprocess.DEVNULL)
    bytes_buffer = b""
    try:
        while running:
            bytes_buffer += proc.stdout.read(4096)
            a, b = bytes_buffer.find(b'\xff\xd8'), bytes_buffer.find(b'\xff\xd9')
            if a != -1 and b != -1:
                jpg = bytes_buffer[a:b+2]; bytes_buffer = bytes_buffer[b+2:]
                with frame_lock: ultimo_frame_jpg = jpg
                frame = cv2.imdecode(np.frombuffer(jpg, dtype=np.uint8), cv2.IMREAD_GRAYSCALE)
                if frame is not None:
                    _, maschera = cv2.threshold(frame, 248, 255, cv2.THRESH_BINARY)
                    cnts, _ = cv2.findContours(maschera, cv2.RETR_EXTERNAL, cv2.CHAIN_APPROX_SIMPLE)
                    if cnts:
                        c = max(cnts, key=cv2.contourArea)
                        if 15 < cv2.contourArea(c) < 2000:
                            M = cv2.moments(c); posX = int(M["m10"] / M["m00"])
                            # --- NUOVE ZONE 13.7 (CENTRO PIU LARGO) ---
                            if posX < 200: comando_led = "A"
                            elif posX > 440: comando_led = "D"
                            else: comando_led = "W"
                        else: comando_led = "X"
                    else: comando_led = "X"
    finally: proc.terminate()

def run_flask():
    app.run(host='0.0.0.0', port=5000, debug=False, use_reloader=False)
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

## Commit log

2026-01-28 chore: create .gitkeep
    chore: init rover/arduino folder
2026-01-28 chore: create .gitkeep
    chore: init rover/raspberry folder
2026-03-23 feat: first version of Arduino Mega firmware
2026-03-23 feat: first version of Raspberry Pi control software
2026-04-13 feat: add front ToF sensor to firmware
2026-04-20 feat: final version of Raspberry Pi software
2026-04-20 feat: full omnidirectional sensor integration
2026-04-25 chore: add Bill of Materials and Technical Diagram
2026-04-25 fix: update README
    Update phase 2 with the two possible subphases
    Update all the colors in the flowcharts for better readibility
    Add setup scripts for fire recognition script
    Fix step down of raspberry batter
    Add arduino serial pins 18 and 19 for rx and tx
    Add raspberry locking and unlocking SD card
    Add battery balance for raspberry with tester buzzer
2026-04-26 feat: add 3D models for dark chamber and GoPro mount
    [estensione.stl, supporto.stl]
2026-07-07 Create Relazione_Finale_Progetto_Dronebot_Holly_Arangio_Ruiz.pdf
    Aggiunta relazione finale di progetto
